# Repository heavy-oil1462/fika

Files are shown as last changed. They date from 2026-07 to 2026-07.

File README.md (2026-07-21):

# fika

An open source DIY cappuccino machine. Minimalist and solid: an oak
slab, two aluminum rails, exposed copper pipes and lead free brass, and
an ESP32 brain running ESPHome with first-class Home Assistant support.

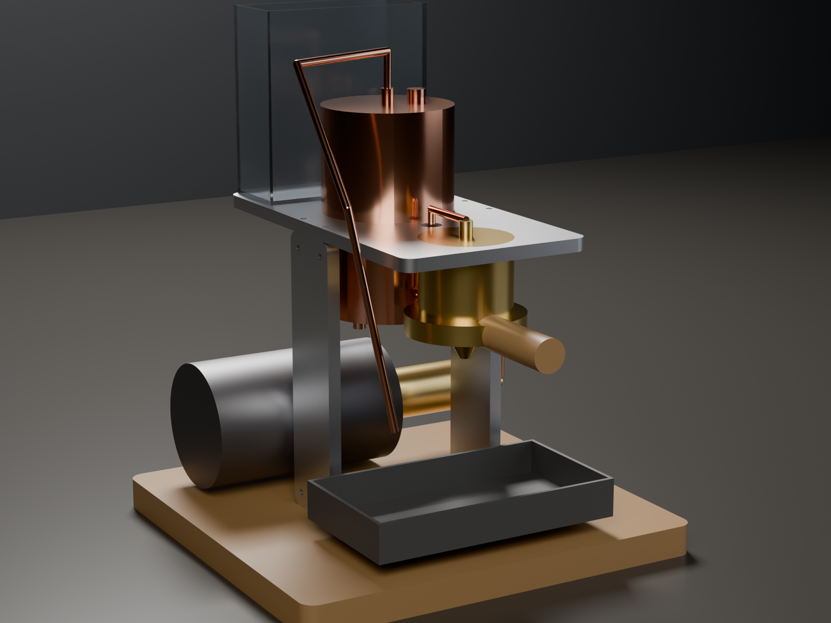
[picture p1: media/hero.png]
fika concept render


*Concept render, generated from the CAD by `scripts/render_hero.py`
(see the hero-render skill); regenerate, never edit. This machine does
not exist: the image shows design intent, not a product.*

## Status: early concept

This project is at the earliest possible stage. No machine exists and
none has ever been built: no frame has been cut, no boiler brazed, no
wire connected. What the repository contains is a parametric layout
model, a firmware skeleton that runs under QEMU, and documents
describing the design intent. Every dimension, setpoint, cost and
claim in these files is an unvalidated estimate and may change
completely. Nothing here is a build guide, and nothing here has been
reviewed for safety. Do not build from these files.

## Philosophy

- Controls are what you already do. Put your cup on the tray: the
  machine recognizes it by weight and arms that cup's brew program.
  Flip the solid brew toggle; the shot stops itself at the target
  beverage weight. Two toggles, a lamp, a beep. No screens.
- Autonomous. Every control loop runs on the ESP32; MQTT and Home
  Assistant observe and adjust setpoints. The machine brews with the
  network cable cut.
- Nothing that does not work. There is no case: the frame is an oak
  slab, two rails and a deck, and a member exists only if it carries a
  component (concepts/open-frame.md). What is left over is copper, so
  the plumbing is routed to be looked at.
- Solid and honest. Mains, heat and pressure are handled by a
  mechanical safety chain that works with the firmware dead
  (concepts/safety-architecture.md). Pressure parts are brass and
  copper, never printed; the parts you touch are oak.
- Deterministic. One parameters file drives CAD, layout checks and
  budgets; one command regenerates every derived artifact; one
  read-only gate verifies everything, runs before every push, and is
  exactly what CI runs.

## Design snapshot

- Single boiler, dual use: brew at 93 C, steam at 125 C (SPECS.md).
- Rotary vane pump + mains motor, OPV at 9 bar.
- 230 V / 50 Hz EU mains, 1400 W element, 10 A circuit friendly.
- Frame: 24 mm oak slab plus 10 mm 6082-T6 rails and deck, all cut on a
  PrintNC; DXF profiles are build products (outputs/dxf/).
- Layout at a glance: outputs/png/main_assembly.png, the fixed-camera
  reference render. Boiler and group seated in the deck, pump under it,
  tank standing on the deck, drip tray that doubles as a scale, exposed
  copper throughout.

## Control system

```
python3 tools/validate.py        # software gate (yaml, esphome, contracts)
scripts/verify_design.sh         # full read-only verify gate
python3 scripts/regen_all.py     # rebuild all derived artifacts
esphome config esphome/example-fika.yaml
```

Real-firmware simulation (no hardware needed): the actual compiled
firmware boots under Espressif QEMU and you poke sensor values from a
debug web page while watching the machine react. See docs/SIMULATION.md
and `.claude/skills/simulator`.

## Toolchain

Nix is optional everywhere. The software gate needs python3 plus
esphome, yamllint and the esphome_skills package: either
`pip install -r requirements.txt` or the pinned devshell
(`nix develop`). The CAD pipeline needs a 2024+
OpenSCAD dev snapshot, resolved as `$OPENSCAD`, then `openscad` on
PATH, then nix; the hero render needs any Blender 4.x the same way.
One caveat is honest by construction: derived artifacts are only
byte-reproducible between identical OpenSCAD builds, so the drift step
of the gate compares bytes when your version matches
outputs/openscad_version.txt and self-skips with a notice when it does
not, while every other step runs at full strength. CI runs the same
gate from pip and the OpenSCAD nightly AppImage, no nix involved.

## Repository structure

- `cad/` - OpenSCAD models; `design_params.scad` is the single source
  of truth for every shared dimension
- `outputs/` - committed build products (STL, DXF, PNG, budgets);
  regenerated by `scripts/regen_all.py`, drift-checked by the gate
- `media/` - the hero render; a build product of
  `scripts/render_hero.py`, kept out of outputs/ because Cycles output
  is not byte deterministic, so the gate cannot drift-check it
- `esphome/` - composable firmware: `fika-base.yaml` + one package per
  capability + example and simulator nodes
- `scripts/`, `tools/` - the pipeline and the gates
- `docs/` - contracts: PROTOCOL, HARDWARE, EXTENDING, SIMULATION
- `concepts/` - design rationale
- `.github/` - CI workflows, path-filtered: validate always, design on
  CAD-side changes, firmware on esphome changes
- `SPECS.md`, `MATERIALS.md`, `TODO.md`

## How to contribute

Fork, branch, and keep the gate green: `scripts/verify_design.sh` must
pass, and anything under `outputs/` must be regenerated in the same
change that alters its sources. Machine-specific configuration belongs
in your private fika-config (docs/EXTENDING.md), not in the stock
packages.

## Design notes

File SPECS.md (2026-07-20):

# fika technical specification

Numbered so discussions can cite sections. Dimensions and setpoints live
in cad/design_params.scad; this file states the design intent around
them. Status caveat: this is a concept-phase specification; none of it
has been built or validated (see Status in README.md).

## 1. Thermal

- Single dual-use boiler: copper shell, nominal 1.0 l fill, brass
  ports, lead free brazing. Vertical cylinder, element through the
  bottom cap.
- 1400 W / 230 V element behind an SSR, PID controlled (ESPHome
  climate). Setpoints: brew 93 C, steam 125 C, firmware cutoff 135 C.
- Heat-up budget from cold: under 6 min (generated proof:
  outputs/budgets/energy_budget.md; gate: verify step 7).

## 2. Hydraulic

- Rotary vane pump on a mains induction motor, low in the chassis for
  noise and center of gravity. OPV at 9 bar bypassing to the tank.
- Path: tank (gravity, standing on the deck above the pump) -> pump ->
  OPV tee -> boiler bottom -> front outlet -> three-way brew valve ->
  group; steam from the boiler top to the wand over the tray. Exposed
  copper lines, brass compression fittings.
- Boiler mechanical relief valve at 12 bar, venting over the tray.
- Group: standard 58 mm E61-compatible portafilter group (cots), bolted
  under the group mount plate.

## 3. Electrical

- 230 V / 50 Hz, 10 A circuit. Heater current 6.1 A leaves margin
  within the 80 percent continuous rule (generated budget).
- Heater path: mechanical thermal cutoff -> thermal fuse -> SSR.
  Pump motor via contactor. ESP32 and sensors are extra-low-voltage
  only. Pin map and wiring: docs/HARDWARE.md.

## 4. Controls

- ESP32 (esp32dev) running ESPHome; Home Assistant over MQTT discovery.
  All control loops local; the machine works with no network
  (docs/PROTOCOL.md).
- Physical controls: two solid toggles (brew, steam), a ready lamp, a
  buzzer. No screens.
- Behavior-driven: drip tray load cell recognizes calibrated cups by
  weight and arms that cup's brew program; shots stop gravimetrically
  at target beverage weight (concepts/cup-recognition.md).

## 5. Safety

- Three layers, firmware last and weakest:
  concepts/safety-architecture.md. Pressure and thermal parts are
  purchased, never printed.
- Every actuator defaults off at boot; actuator commands are never
  retained on the broker.

## 6. Frame and fabrication

- Open frame, no enclosure: an oak base slab, two aluminum rails, one
  aluminum deck. A member exists only if it carries a component
  (concepts/open-frame.md), so the copper runs are the visible surface
  of the machine.
- The deck seats the boiler and the group in bored seats, carries the
  tank, and passes the tank outlet and brew riser through two bores.
- Oak where hands and the counter meet the machine: the base slab and
  the portafilter handle (which must not conduct boiler heat).
- All flat parts are CNC-milled on the PrintNC, oak included; one bolt
  size (M5) throughout. DXF profiles are pipeline outputs
  (outputs/dxf/).
- Every cad part header carries a fabrication tag: cnc, print, cots,
  lib or assembly (gate: validate `fabtags`).

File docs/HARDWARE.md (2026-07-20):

# HARDWARE - electronics, pins and wiring

The mechanical and hydraulic BOM lives in MATERIALS.md. This file covers
the control electronics around the ESP32. Mains wiring is sketched here
for the contract only; SPECS.md section 5 and
concepts/safety-architecture.md define the safety chain that must exist
regardless of what the firmware does. Status caveat: concept phase;
none of this has been wired or tested on hardware (see Status in
README.md).

## Bill of materials (electronics)

| Qty | Part | Notes | ~Cost |
|---|---|---|---|
| 1 | ESP32 devkit (esp32dev) | the brain, 5 V USB supply | 5 EUR |
| 1 | Mean Well RS-15-5 or similar | 5 V PSU from mains | 10 EUR |
| 1 | SSR 25 A zero-crossing + heatsink | heater element switch | 10 EUR |
| 1 | Mechanical thermal cutoff, manual reset | on boiler shell, opens above max_temp_c | 5 EUR |
| 1 | Thermal fuse, one-shot | last resort, in series with the cutoff | 2 EUR |
| 1 | Relay/contactor, 230 V coil rating for motor load | pump motor switch | 8 EUR |
| 1 | Relay or MOSFET board | brew solenoid drive | 3 EUR |
| 1 | PT100 probe, M4 stud or pocket mount | boiler temperature | 8 EUR |
| 1 | MAX31865 breakout | PT100 amplifier, SPI | 5 EUR |
| 1 | TAL220 bar load cell, 1 kg | under the drip tray | 5 EUR |
| 1 | HX711 breakout | load cell amplifier | 3 EUR |
| 2 | Solid metal toggle switch | brew and steam controls | 8 EUR |
| 1 | Indicator lamp, 5 V | ready light | 2 EUR |
| 1 | Piezo buzzer, active | shot-finished beep | 1 EUR |

## Default pin map

Every pin is a substitution so a private fika-config can rewire without
touching the packages. Constraint column rules are hard: actuators must
never sit on strapping pins (GPIO0/2/12/15) that glitch at boot, and
GPIO34-39 are input only with no internal pulls.

| Function | GPIO | Substitution | Constraint |
|---|---|---|---|
| Heater SSR | GPIO25 | heater_pin | never a strapping pin |
| Pump relay | GPIO26 | pump_pin | never a strapping pin |
| Brew solenoid | GPIO27 | valve_pin | never a strapping pin |
| SPI clock | GPIO18 | spi_clk_pin | - |
| SPI MISO | GPIO19 | spi_miso_pin | - |
| SPI MOSI | GPIO23 | spi_mosi_pin | - |
| MAX31865 CS | GPIO5 | max31865_cs_pin | strapping pin, input at boot is fine for CS |
| HX711 DOUT | GPIO32 | hx711_dout_pin | - |
| HX711 SCK | GPIO33 | hx711_clk_pin | - |
| Brew switch | GPIO34 | brew_switch_pin | input only, external pull-down |
| Steam switch | GPIO35 | steam_switch_pin | input only, external pull-down |
| Ready lamp | GPIO21 | lamp_pin | - |
| Buzzer | GPIO22 | buzzer_pin | - |

## Wiring overview

    mains 230 V ---+--- 5 V PSU --- ESP32
                   |
                   +--- thermal cutoff --- thermal fuse --- SSR --- heater element
                   |                                         ^
                   |                                         | GPIO25
                   +--- contactor --- pump motor             |
                             ^                             ESP32
                             | GPIO26 (coil via driver)
                             |
                   +--- solenoid valve (via relay, GPIO27)

    ESP32 SPI (18/19/23/5) --- MAX31865 --- PT100 in boiler well
    ESP32 (32/33) --- HX711 --- load cell under drip tray
    GPIO34/35 --- brew / steam toggles (to 3V3 via switch, 10k pull-down)
    GPIO21/22 --- lamp / buzzer

The ESP32 side stays extra-low-voltage everywhere: it drives coils and
gates, never a mains conductor. Heater power flows through the
mechanical cutoff and the thermal fuse before the SSR, so two
independent hardware links open even if the SSR welds shut and the
firmware is gone.

## Calibration

Scale, two point: with the tray empty read the raw HX711 value into
`scale_raw_zero`; place a known 1000 g mass and read `scale_raw_1kg`.
Set both in your fika-config substitutions.

Cup table: weigh each cup empty on the calibrated tray, note the grams
into `cupN_tare_g`, pick `cupN_target_g` for the drink. Cups must differ
by more than 2 x cup_tolerance_g (10 g) or recognition refuses to guess
(by design, see concepts/cup-recognition.md).

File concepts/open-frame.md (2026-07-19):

# Open frame

**Purpose:** there is no case. The machine is held by three kinds of
member and nothing else, so every part you can see is a part that does
something.

## The rule

A member exists only if it carries a component. That leaves:

- the oak base slab: the mass that stands on the counter, damps the
  pump, and gives every other part something to bolt to,
- two aluminum rails: they carry the deck, flank the boiler on the way
  up, and touch nothing else (scripts/check_layout.py enforces the
  clearance),
- one aluminum deck: it seats the boiler and the group in bored seats,
  carries the tank, and passes the tank outlet and the brew riser
  through two more bores.

Panels, covers and a back wall carry nothing, so they are not in the
design. The consequence is that the copper is the visible surface of
the machine, which is why the runs are routed to be looked at rather
than hidden: shortest sensible path, right angles, no crossings.

## What follows from it

- Every layout number has to be honest, because nothing is concealed.
  The layout checks grew accordingly: rails clear all components, the
  deck leaves material around each bore, the tank sits on the deck, and
  nothing overhangs the slab.
- The tank stands on the deck rather than hanging in a cabinet, which
  puts its outlet well above the pump inlet and keeps the suction line
  flooded (concepts/single-boiler-thermal.md covers the thermal side).
- Hot parts are reachable by design, so the safety chain is mechanical
  and independent of firmware (concepts/safety-architecture.md), and
  the parts you touch are oak: the base and the portafilter handle.
- Stiffness has to come from the members themselves. The deck is a
  balanced beam, loaded by the group forward of the rails and the tank
  behind them; rail gussets are a phase 2 detail (TODO.md).

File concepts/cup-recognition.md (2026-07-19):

# Cup recognition

**Purpose:** the machine's controls should mostly be what the user
already does. Placing a cup on the tray is the order: the machine
recognizes which cup it is by weight and prepares that cup's drink, and
the shot stops itself at the right beverage weight.

## How

A bar load cell under the drip tray (cup_scale.yaml) weighs the tray
continuously. While idle, a stable weight within cup_tolerance_g of
exactly one calibrated cup tare selects that cup: the target beverage
weight is set and the detected cup is published. Flip the brew toggle
and the machine opens the valve, runs the pump, and stops
gravimetrically when beverage weight (current minus tare) reaches the
target.

## Rules that keep it honest

- Ambiguity selects nothing. Two cups within tolerance of the reading
  means no program is chosen; the machine never guesses. Calibrated
  tares must therefore differ by more than twice the tolerance.
- The matching rule exists once, in tools/cup_match.py, and the ESPHome
  lambda mirrors it line for line; tools/validate.py pins the shared
  tolerance and tools/test_cup_match.py pins the behavior.
- The brew toggle is still the commitment. Recognition arms a program,
  the human starts it; nothing pours because a cup appeared.
- No cup, no brew: the toggle logs a refusal if nothing was recognized.

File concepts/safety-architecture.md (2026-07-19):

# Safety architecture

**Purpose:** define the layered protection around 230 V mains, a
pressurized boiler and a 125 C surface, such that no single failure,
including a complete firmware failure, leaves the machine dangerous.

## Three layers, weakest last

1. Mechanical, always live. The heater circuit passes through a
   manual-reset thermal cutoff mounted on the boiler shell and a
   one-shot thermal fuse in series, before the SSR. The boiler carries a
   mechanical relief valve (relief_bar, 12 bar) that vents over the
   drip tray. The pump has an OPV (opv_bar, 9 bar) bypassing back to the
   tank. None of these know the ESP32 exists.
2. Electrical topology. The ESP32 side is extra-low-voltage everywhere;
   it drives the SSR input, a contactor coil and a solenoid driver.
   Actuator GPIOs avoid boot-glitching strapping pins and every actuator
   defaults off at boot (docs/HARDWARE.md).
3. Firmware interlocks (packages/safety.yaml). Over-temperature above
   max_temp_c or a dead boiler sensor latches a fault: heater off, pump
   off, valve closed, until the machine is power cycled. Steam mode and
   brewing exclude each other. This layer improves behavior; it is
   explicitly not the protection.

## Rules

- Pressure and thermal parts are cots brass/copper, never printed
  (MATERIALS.md marks them).
- The relief valve and OPV setpoints live in cad/design_params.scad;
  max_temp_c spans CAD and firmware and is swept by tools/validate.py.
- Any new actuator package must default off at boot and state its
  interlocks in the banner.

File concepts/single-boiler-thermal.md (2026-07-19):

# Single dual-use boiler

**Purpose:** one copper boiler serves both espresso water (~93 C) and
steam (~125 C), keeping the machine minimal: one vessel, one element,
one PID.

## Why single boiler

Dual boilers and heat exchangers buy simultaneous brew and steam at the
cost of a second vessel or muddier brew temperature control. fika's
aesthetic and philosophy is a small number of solid parts; waiting
half a minute between shot and milk is an accepted trade. The PID
retargets between two setpoints (steam_mode.yaml); brewing is
interlocked at steam temperature because 125 C water would scorch the
shot.

## Thermal notes

- 1.0 l fill, 1400 W element: about 4 min from cold to brew temperature
  (outputs/budgets/energy_budget.md is the generated truth; the verify
  gate keeps it under 6 min).
- The element enters the bottom cap; the PT100 sits in a well at mid
  height, away from the element so the PID sees water, not element skin.
- Steam is drawn from the top; brew water from low in the vessel via
  the front outlet. Fresh feed enters the bottom, which also tempers
  brew-temperature droop during a shot.
- The vessel is copper with brass ports, silver brazed with lead free
  alloy. Purchased or commissioned, never printed and never improvised
  (concepts/safety-architecture.md).

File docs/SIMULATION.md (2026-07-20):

# Simulating the machine - the real firmware, no hardware

fika ships a simulator that is not a re-implementation of the control
logic: it is the actual firmware, compiled for a stock esp32dev board
and executed under Espressif's QEMU fork, wired to your MQTT broker and
therefore your Home Assistant. The cup recognition, gravimetric stop,
PID retargeting and fault latching you observe are made by the same C++
that runs in the machine.

```
+------------------------- podman container --------------------------+
|                                                                     |
|  +-------------------------------+      +------------------------+  |
|  | QEMU (machine esp32)          | SNTP | webui.py               |  |
|  |  REAL firmware:               |----->|  simulated clock       |  |
|  |  sim-fika.yaml                | :123 |  sensor injections     |  |
|  |  = fika-base                  |      |  live entity view      |  |
|  |  + radio-openeth (emu eth)    |      +-----------^------------+  |
|  |  + sim-sensors (injectable)   |                  | http :8080    |
|  |  + REAL logic/actuators       |                  |               |
|  +---------------+---------------+                  |               |
+------------------+----------------------------------+---------------+
                   | MQTT (discovery, telemetry,      |
                   v        retained setpoints)     browser
            YOUR broker ---> YOUR Home Assistant
```

The simulator engine (container build, web UI, QEMU glue) lives in the
shared [esphome-skills](https://github.com/heavy-oil1462/esphome-skills)
package; the fika side is `tools/project.py` (injections, presets, node
names) and `tools/test_sim.py` (assertions).

## Quickstart

```bash
python3 tools/sim_container.py build                # once (~minutes)
python3 tools/sim_container.py run \
    --broker 192.168.1.10 --username fika --password ...
python3 tools/sim_container.py logs                 # firmware serial console
```

Open http://localhost:8080: sliders for the boiler temperature and cup
weight, toggles for the brew and steam switches, presets (cold start,
ready with cup, brewing), and a live view of everything the node
publishes. The node appears in Home Assistant via MQTT discovery as
`sim-fika`, indistinguishable from hardware.

The first `run` compiles the firmware inside the container against your
broker settings; the cache volume makes later starts fast. If the
broker runs on the container host, use `--broker
host.containers.internal` (the entrypoint resolves it to an IP before
baking it into the firmware; QEMU's user-mode network cannot see
container DNS).

## How each input reaches the real firmware

| Input | Mechanism |
|---|---|
| Sensor values | Retained MQTT topics `fika/<node>/sim/<key>`; packages/sim-sensors.yaml subscribes with the real entity ids (`boiler_temp`, `cup_weight`, `brew_switch`, `steam_switch`) so the stock logic packages run unmodified |
| Time of day | webui.py answers the firmware's SNTP queries (`sntp_server: 10.0.2.2`, re-sync every 15 s) with an offset clock |
| Setpoints | Nothing special: the standard retained command topics (PROTOCOL.md); edit `brew_target_weight` from HA or the UI like on hardware |

Until a value is injected a sensor has no state (NaN) and the
fail-safes behave exactly as with broken hardware: after
`sensor_grace_s` of NaN boiler readings, safety.yaml latches a fault.

Things worth trying: set the boiler to 93 and a cup of 210 g and watch
`detected_cup` flip to cappuccino and the lamp logic report ready; flip
brew and pour by raising cup_weight toward 360 g to see the gravimetric
stop; push the boiler past 135 to watch the fault latch kill the heater.

## The automated version: tools/test_sim.py

The same loop, CI-style: throwaway authenticated mosquitto, web UI
driven over HTTP, assertions on the broker:

```bash
sudo -E nix develop .#sim -c python3 tools/test_sim.py
```

Asserts boot + discovery, boiler_temp and cup_weight injection round
trips, cup recognition reacting to a 210 g cup, and switch injections
reaching their binary sensors. Requirements: an esphome that can
compile, `qemu-esp32` (in the `.#sim` devshell via the
nix-qemu-espressif flake input; kept out of the default shell because
it may build QEMU from source once), and the ability to bind udp/123
(root/CAP_NET_BIND_SERVICE; lwIP's SNTP port is not configurable).
Slow (a compile plus emulated boot time); deliberately not part of the
default validation gate.

## Limitations

- Not cycle-accurate: QEMU timing is roughly wall clock; good enough
  for second-scale brew logic, do not benchmark the PID on it.
- GPIO goes nowhere: the SSR, pump relay and valve drive emulated pins;
  observe actuators via their entities (which is what HA sees too).
- The PID heats nothing: boiler_temp only changes when you move the
  slider, so closed-loop thermal behavior cannot be studied, only the
  mode/setpoint/fault logic around it.
- OTA and safe mode exist but are pointless in a container that
  rebuilds from source each config change.

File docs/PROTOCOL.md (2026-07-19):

# PROTOCOL - the MQTT and entity id contract

This file is the contract between the firmware packages, the simulator,
Home Assistant, and any future consumer. If you change a semantic here,
change every producer and consumer in the same commit. tools/validate.py
(`protocol` check) asserts that the id table below exactly matches the
`Provides:` declarations in `esphome/packages/*.yaml`.

## Naming chain

One name flows through the whole stack. Rename only with a sweep across
all of them:

    entity name "Boiler Temperature"
      -> object_id boiler_temp
      -> MQTT topic fika/<node>/sensor/boiler_temp/state
      -> Home Assistant entity sensor.<node>_boiler_temperature

Topic tree: `<mqtt_root>/<node>/<component>/<object_id>/{state,command}`
with `mqtt_root` = `fika`. Text sensors pin their `state_topic`
explicitly so they never land in `sensor/` (see fika-base.yaml).

The temperature setpoints (`brew_temp_c`, `steam_temp_c`, `max_temp_c`)
also span `cad/design_params.scad` and the packages; tools/validate.py
(`temps` check) owns that sweep set.

## Retention rules

- Setpoints are retained (`brew_target_weight`): they must survive a
  restart or broker outage.
- Actuator commands are never retained (`pump`, `brew_valve`,
  `steam_mode`): a replayed command must not start a pump.
- `fika/<node>/status` is retained online/offline (broker LWT).
- Discovery messages are retained (`discovery_retain: true`).

All control loops run on the ESP32. MQTT and Home Assistant are
observation and setpoint adjustment only; the machine brews with the
network down.

## Entity id contract

| object_id | type | unit | retained command | provided by |
|---|---|---|---|---|
| boiler_temp | sensor | C | - | boiler_sensor, sim-sensors |
| boiler | climate | C | no | boiler_pid |
| heater_duty | sensor | % | - | boiler_pid |
| steam_mode | switch | - | no | steam_mode |
| pump | switch | - | no | pump |
| brew_valve | switch | - | no | brew_valve |
| cup_weight | sensor | g | - | cup_scale, sim-sensors |
| scale_tare | button | - | no | cup_scale |
| detected_cup | text_sensor | - | - | cup_logic |
| brew_target_weight | number | g | yes | cup_logic |
| beverage_weight | sensor | g | - | cup_logic |
| brewing | binary_sensor | - | - | cup_logic |
| brew_switch | binary_sensor | - | - | switches, sim-sensors |
| steam_switch | binary_sensor | - | - | switches, sim-sensors |
| machine_status | text_sensor | - | - | status |
| fault | binary_sensor | - | - | safety |

Interoperability rule: swapping hardware means writing a package that
provides the same object_id with the same unit. Nothing else may need to
change.

`machine_status` values: `heating`, `ready`, `brewing`, `steam`,
`fault`. `detected_cup` values: a calibrated cup name or `none`.

## Simulator injection topics

The simulator (docs/SIMULATION.md) feeds sensors through retained
topics of the form `fika/<node>/sim/<key>`:

    fika/sim-fika/sim/boiler_temp     float C
    fika/sim-fika/sim/cup_weight      float g
    fika/sim-fika/sim/brew_switch     0/1
    fika/sim-fika/sim/steam_switch    0/1

tools/validate.py (`sim` check) asserts these keys equal the web UI's
INJECTIONS and the mqtt_subscribe topics in packages/sim-sensors.yaml.

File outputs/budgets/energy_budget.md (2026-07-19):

# Energy budget

Generated by tools/energy_budget.py from cad/design_params.scad.
Regenerate with scripts/regen_all.py, never edit by hand.

## Electrical

- heater power: 1400 W at 230 V
- heater current: 6.09 A
- breaker: 10 A, continuous limit 8.0 A (80%)
- margin to continuous limit: 1.91 A

## Thermal

- boiler fill: 1.00 kg water, shell 1.21 kg copper
- ambient 20 C to brew 93 C: 340 kJ
- heat-up at 1400 W: 4.0 min
- margin to the 6 min budget: 2.0 min

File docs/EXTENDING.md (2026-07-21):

# EXTENDING - adapt fika without forking it

The core rule from frodas applies unchanged: base and the stock packages
are never edited for a specific machine. Your configuration is a package
list plus substitutions.

## Your private fika-config

Keep your node config (pins, cup table, secrets) in a private repo
cloned inside your fika checkout; fika gitignores `fika-config/`:

    cd fika
    git clone <your-private-config-repo> fika-config
    esphome run fika-config/fika.yaml

Start it by copying `esphome/example-fika.yaml` and
`esphome/secrets.yaml.example`, keep the packages your build has
hardware for, and override substitutions:

    substitutions:
      cup1_name: lungo
      cup1_tare_g: "138.0"
      cup1_target_g: "90.0"
      heater_pin: GPIO25

    packages:
      base: !include ../esphome/fika-base.yaml
      radio: !include ../esphome/packages/radio-wifi.yaml
      # ... the stock list from example-fika.yaml

Alternatively use ESPHome remote packages pinned by ref against
github.com/heavy-oil1462/fika.

## Adding hardware

New hardware means a new package, not an edit. Write
`packages/sensor-<thing>.yaml` with the boxed banner (Substitutions and
Provides sections; the Provides ids are parsed by tools/validate.py) and
provide existing object_ids where you replace stock hardware: a package
that publishes `boiler_temp` in C is a drop-in boiler sensor whatever
the silicon (docs/PROTOCOL.md, interoperability rule).

## Adding a cup

The stock table has two cups as substitutions (cup_logic.yaml). More
cups currently means extending cup_logic.yaml's lambda and the mirror in
tools/cup_match.py together, plus tools/test_cup_match.py; the table is
deliberately substitutions-only until someone needs more than a few
cups. Keep tares at least 2 x cup_tolerance_g apart.

## Checks

Whatever you change: `python3 tools/validate.py`, and before any commit
`scripts/verify_design.sh` (the verify skill). CI runs the same gate
(.github/workflows/), so a green local run means a green PR.

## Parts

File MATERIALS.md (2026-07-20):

# Material and component list (BOM)

Grouped by subsystem. CAD back-references point at the owning model.
The electronics detail table with costs lives in docs/HARDWARE.md.
Pressure and thermal parts are cots only: never printed, never
improvised. Status caveat: this is a concept-phase list; no part on it
has been bought or fitted (see Status in README.md).

## Frame and mechanics

The frame is open: three members, each carrying a component
(concepts/open-frame.md). DXF profiles for all of them are pipeline
outputs in outputs/dxf/.

- European oak slab, 24 mm, 330 x 320: the base everything bolts to
  (cad/frame.scad, profile `base`). Cut on the PrintNC like the metal.
  Oiled, not lacquered, so it can be re-oiled after spills.
- 6082-T6 aluminum plate, 10 mm: two rails (profile `rail`) and one
  deck (profile `deck`). The deck is bored to seat the boiler and the
  group and to pass the tank outlet and brew riser.
- M5 stainless bolts throughout, one bolt size for every frame joint
  (bolt_hole_d in cad/design_params.scad). Threaded inserts in the oak.
- Printed drip tray, PETG (cad/drip_tray.scad); replace with folded
  stainless later (TODO phase 2).

## Boiler and thermal (cots only)

- Copper boiler, ~102 mm OD x 160 mm, 1.0 l, brass ports
  (cad/boiler.scad envelope). Commissioned or salvaged; lead free
  brazing.
- Heating element 1400 W / 230 V, bottom entry.
- Mechanical relief valve, 12 bar.
- Thermal cutoff (manual reset) and one-shot thermal fuse, boiler
  shell mount.
- PT100 probe + MAX31865 (docs/HARDWARE.md).
- Insulation wrap for the shell (keeps the exposed-copper look on the
  pipes, not the vessel).

## Hydraulics (cots only)

- Rotary vane pump head, Procon/Fluid-o-Tech class (cad/pump.scad
  envelope), with 9 bar OPV.
- Mains induction motor, ~100 mm frame (cad/pump.scad envelope).
- Three-way brew solenoid valve, 230 V.
- 58 mm portafilter group (cad/group.scad envelope), with a turned oak
  handle: the one part of the group you hold, and the one that must not
  conduct boiler heat into your hand.
- Copper tube 6 mm OD (pressure and steam), 8 mm OD (suction), lead
  free brass compression fittings (cad/hydraulic_path.scad).
- Water tank ~1.3 l, glass or stainless, standing on the deck so the
  suction line stays flooded (cad/tank.scad envelope).

## Electronics

- See the table in docs/HARDWARE.md (ESP32, SSR, contactor, MAX31865,
  HX711 + TAL220 load cell, toggles, lamp, buzzer, 5 V PSU).

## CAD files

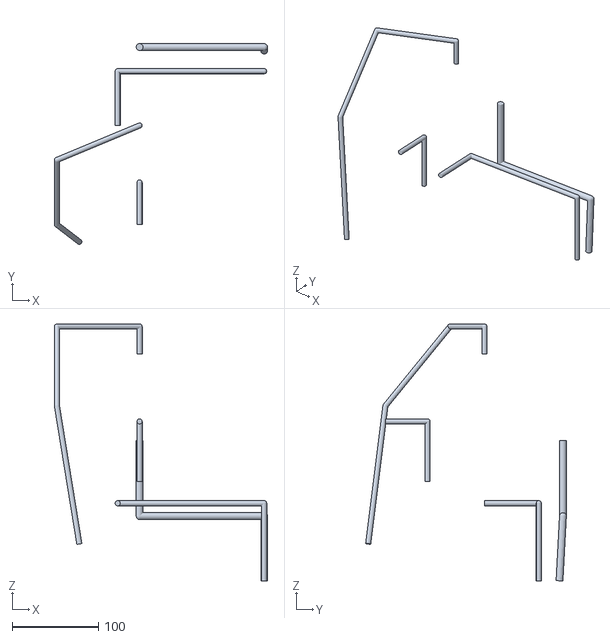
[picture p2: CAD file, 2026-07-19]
outputs/stl/hydraulic_path.stl
247.5 x 233.0 x 298.2

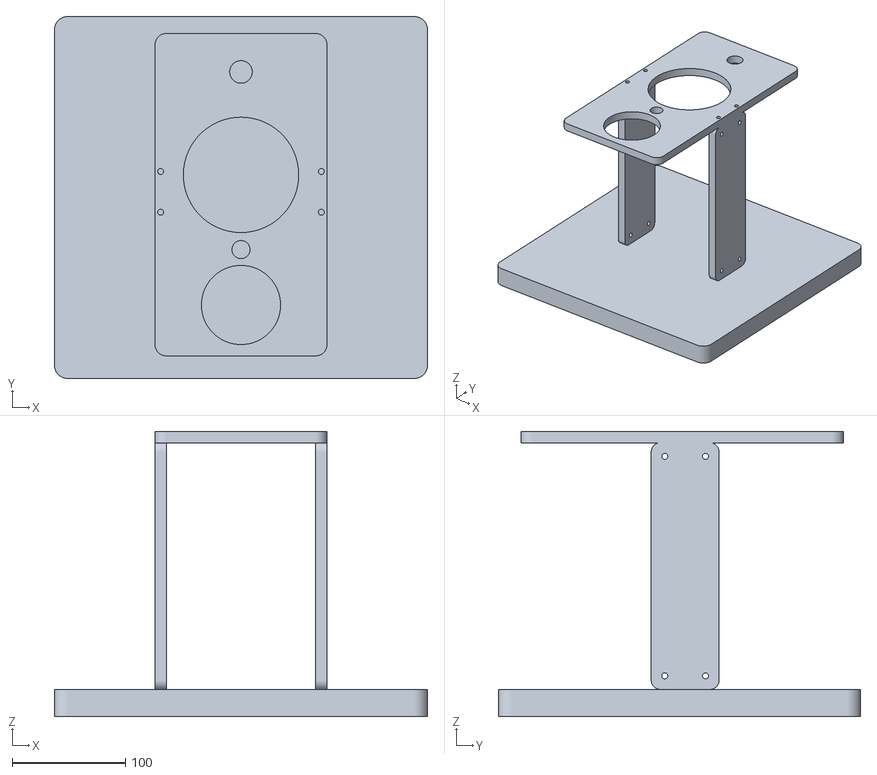
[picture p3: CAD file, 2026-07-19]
outputs/stl/frame.stl
330.0 x 320.0 x 252.0

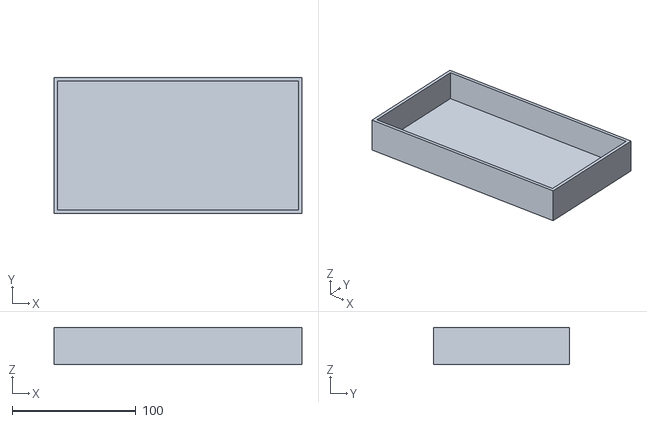
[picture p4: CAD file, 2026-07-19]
outputs/stl/drip_tray.stl
200.0 x 110.0 x 30.0

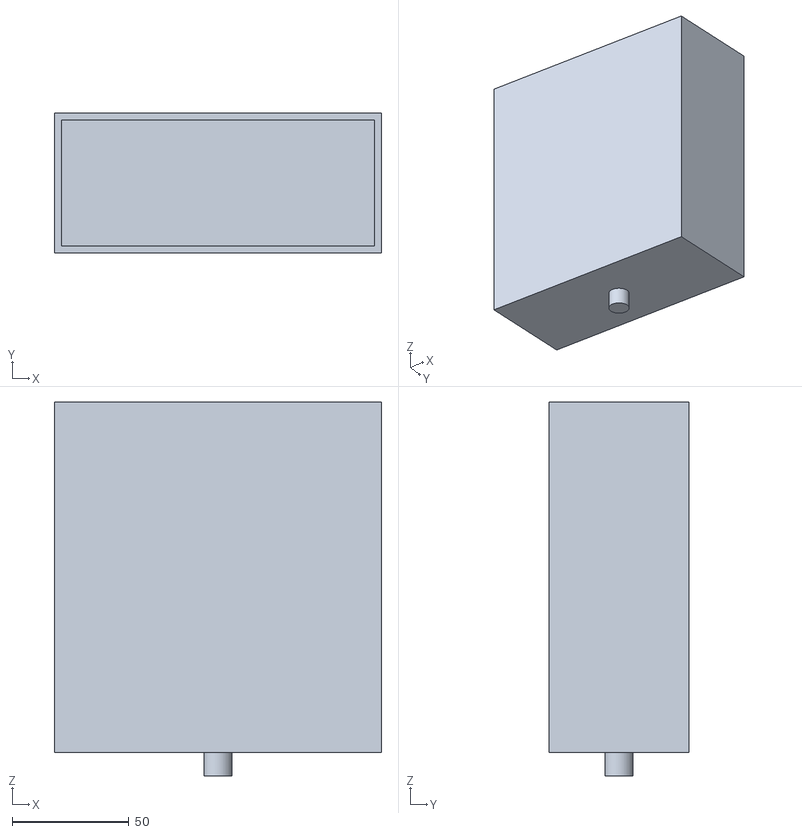
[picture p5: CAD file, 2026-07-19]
outputs/stl/tank.stl
140.0 x 60.0 x 160.0

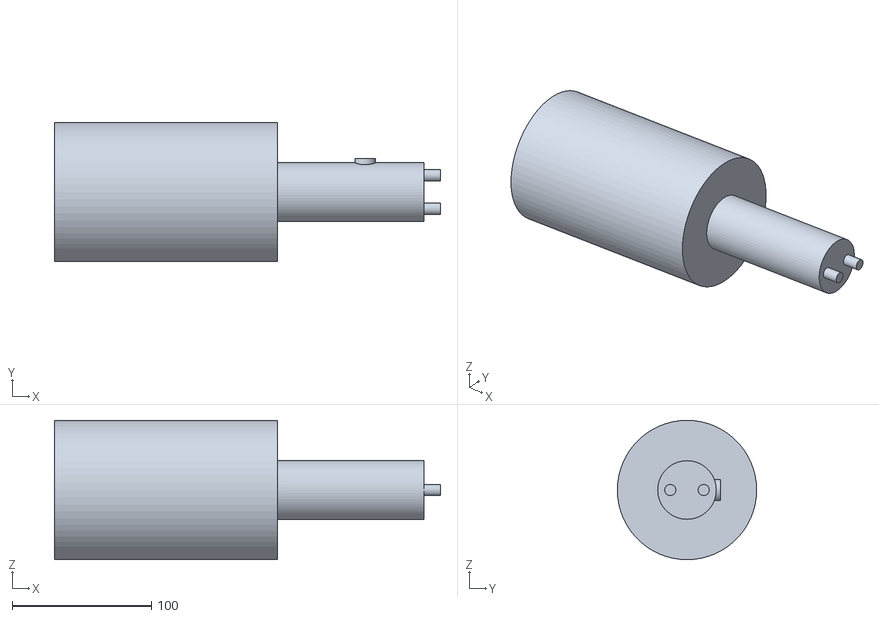
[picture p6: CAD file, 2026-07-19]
outputs/stl/pump.stl
277.0 x 100.0 x 100.0

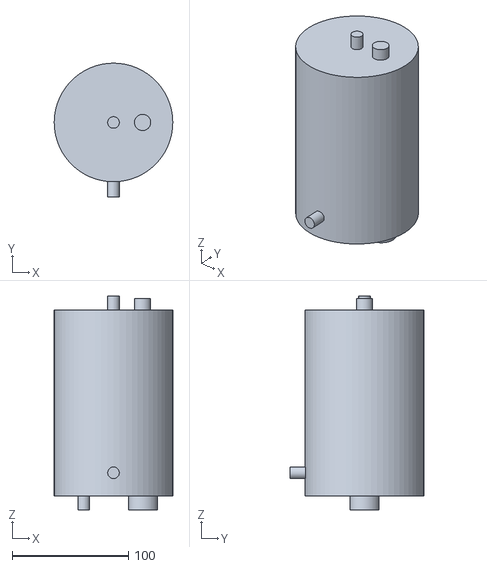
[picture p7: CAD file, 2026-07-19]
outputs/stl/boiler.stl
102.0 x 115.0 x 184.0

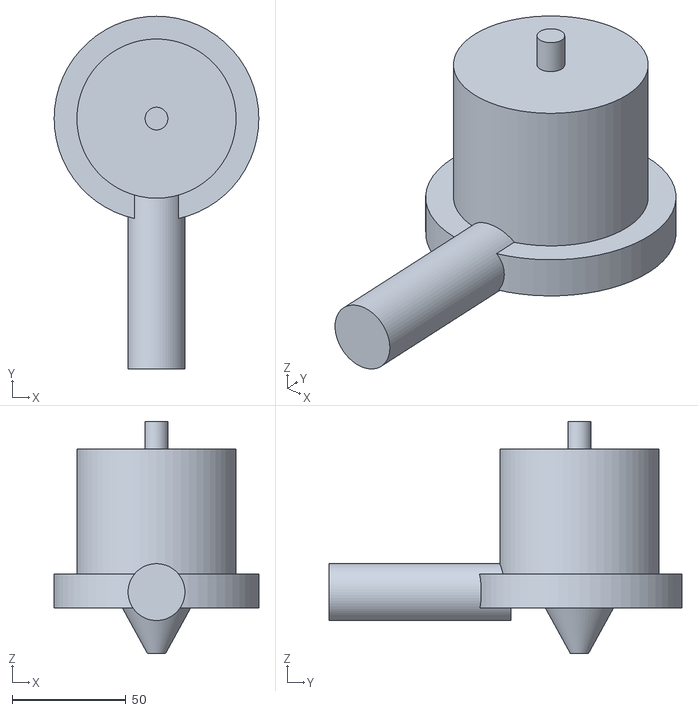
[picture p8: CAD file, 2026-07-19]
outputs/stl/group.stl
90.0 x 155.0 x 102.0

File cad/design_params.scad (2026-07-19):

/*
 * fika - shared design parameters, the single source of truth.
 *
 * Read by every cad/*.scad (include <design_params.scad>) and re-parsed by
 * scripts/design_params.py for scripts/check_layout.py and
 * tools/energy_budget.py, so a value changed here flips the whole pipeline
 * at once. scripts/check_params.py fails the build if any other .scad
 * shadows a name defined here.
 *
 * Keep every line a plain literal: name = value; (numbers, booleans, flat
 * vectors). No arithmetic - derived values are computed by the consumers.
 *
 * Units: mm, deg C, W, V, A, bar, g unless noted.
 * Coordinates: origin at the center of the base plate top surface.
 * X right, Y toward the back, Z up. Positions are component reference
 * points noted per name.
 */

// open frame: an oak base slab carrying two aluminum rails and one deck
// plate that holds the boiler and the group through bored seats. There is
// no enclosure - every member carries a component, and everything else is
// left exposed. Heights are derived from the components they hold.
frame_w = 330;          // base slab width (clears the pump and its ports)
frame_d = 320;          // base slab depth
base_t = 24;            // oak slab thickness (mass and damping; z -base_t..0)
frame_plate_t = 10;     // aluminum rails and deck
rail_inset = 66;        // rail inner face from center (flanks the boiler)
rail_front = 135;       // rail front edge (clears the drip tray)
rail_back = 195;        // rail back edge (clears the pump)
deck_front = 20;        // deck front edge (leaves plate around the group bore)
deck_back = 305;        // deck back edge (carries the tank behind the boiler)

// boiler (single, dual use, copper shell; position = bottom center)
boiler_od = 102;
boiler_h = 160;
boiler_wall = 2;
boiler_x = 0;
boiler_y = 180;
boiler_z = 150;
boiler_volume_l = 1.0;  // nominal fill, used by the energy budget

// heater and mains
heater_power_w = 1400;
mains_voltage = 230;
mains_breaker_a = 10;
brew_temp_c = 93;
steam_temp_c = 125;
max_temp_c = 135;       // firmware hard cutoff; mechanical cutoff above this

// pump: rotary vane head + mains motor, axis along X at the rear base
// (position = axis center; assembly centered on pump_x)
pump_head_d = 42;
pump_head_l = 105;
motor_d = 100;
motor_l = 160;
pump_x = 0;
pump_y = 255;
pump_z = 55;
opv_bar = 9;            // pump bypass back to reservoir
relief_bar = 12;        // boiler mechanical safety relief valve

// brew group and cup zone (position = group axis at tray center)
group_od = 70;
group_h = 90;
group_x = 0;
group_y = 65;
cup_clearance_h = 95;   // spout height above the tray top
cup_max_d = 90;

// drip tray with load cell scale (tray_z = top of load cell + gap)
tray_w = 200;
tray_d = 110;
tray_h = 30;
tray_y = 15;            // tray front edge
tray_z = 13;
loadcell_l = 55;        // TAL220-class bar load cell
loadcell_w = 12.7;
loadcell_h = 12.7;
scale_capacity_g = 1000;

// water tank: stands on the deck behind the boiler, so the outlet sits
// well above the pump inlet and the suction line stays flooded.
// tank_z must equal the deck top (scripts/check_layout.py asserts it).
tank_w = 140;           // stays within the deck it stands on
tank_d = 60;
tank_h = 150;
tank_y = 241;
tank_z = 228;

// plumbing, copper lines (suction from the tank is larger bore)
brew_line_od = 6;
brew_line_wall = 1;
steam_line_od = 6;
suction_line_od = 8;

// fasteners (one bolt size for every frame joint, M5 with clearance)
bolt_hole_d = 5.3;

// layout rules (scripts/check_layout.py)
clearance = 10;         // minimum gap between component envelopes, and
                        // between the rails and anything they do not carry

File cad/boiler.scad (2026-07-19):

/*
 * fika - boiler envelope.
 * Purpose: layout placeholder for the single dual-use copper boiler.
 *          Origin at the bottom cap center. Stubs mark the ports: element
 *          boss and feed inlet below, brew outlet on the front face low,
 *          steam outlet and safety relief valve on top.
 * Material: copper shell, brass ports (pressure vessel, never printed)
 * Fabrication: cots
 */

include <design_params.scad>

$fn = 60;

module boiler() {
    color("#b87333") {
        cylinder(d = boiler_od, h = boiler_h);
        // heating element boss, enters through the bottom cap
        translate([boiler_od / 4, 0, -12]) cylinder(d = 25, h = 14);
        // feed water inlet from the pump
        translate([-boiler_od / 4, 0, -12]) cylinder(d = 10, h = 14);
        // brew outlet to the group, front face, low
        translate([0, -boiler_od / 2 + 2, 20])
            rotate([90, 0, 0]) cylinder(d = 10, h = 15);
        // steam outlet, top center
        translate([0, 0, boiler_h]) cylinder(d = 10, h = 12);
        // safety relief valve port, top
        translate([25, 0, boiler_h]) cylinder(d = 14, h = 10);
    }
}

boiler();

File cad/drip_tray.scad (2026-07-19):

/*
 * fika - drip tray and load cell.
 * Purpose: layout placeholder for the drip tray that doubles as the cup
 *          scale platform. Tray origin at the center of its footprint,
 *          bottom at z 0. loadcell_bar() is the TAL220-class bar the tray
 *          sits on, placed by the assembly between base plate and tray.
 * Material: printed tray for the foundation, load cell off the shelf
 * Fabrication: print
 */

include <design_params.scad>

$fn = 60;

module drip_tray() {
    color("#333333") difference() {
        translate([-tray_w / 2, -tray_d / 2, 0])
            cube([tray_w, tray_d, tray_h]);
        translate([-tray_w / 2 + 3, -tray_d / 2 + 3, 4])
            cube([tray_w - 6, tray_d - 6, tray_h]);
    }
}

// cots: bar load cell under the tray center
module loadcell_bar() {
    color("#999999") translate([-loadcell_l / 2, -loadcell_w / 2, 0])
        cube([loadcell_l, loadcell_w, loadcell_h]);
}

drip_tray();

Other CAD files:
outputs/dxf/frame_base.dxf
outputs/dxf/frame_deck.dxf
outputs/dxf/frame_rail.dxf
cad/frame.scad
cad/group.scad
cad/hydraulic_path.scad
cad/main_assembly.scad
cad/pump.scad
cad/tank.scad

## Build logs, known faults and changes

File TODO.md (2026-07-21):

# TODO

## Phase 1 - foundation (this PR)

- [x] Repo conventions: params single source of truth, guards, flake
- [x] Layout CAD: frame, envelopes, hydraulic path, assembly, DXF/STL/PNG
- [x] Pipeline: regen_all + read-only verify gate + drift check
- [x] Firmware skeleton: base, packages, contracts, example + sim nodes
- [x] QEMU simulator with injection web page
- [x] Docs: SPECS, MATERIALS, PROTOCOL, HARDWARE, EXTENDING, concepts
- [x] CI running the verify gate (.github/workflows/: validate on every
      change, the full design gate and the firmware build path-filtered;
      no nix in CI - pip plus the OpenSCAD snapshot AppImage, byte drift
      self-skips unless the version matches outputs/)

## Phase 2 - mechanical detail

- [ ] Rail stiffness: the deck is a balanced beam on two slender rails,
      so size the rails properly or add gussets at the slab and deck
- [ ] Frame joinery: threaded inserts in the oak, real hole patterns
- [ ] Boiler seat detail: a collar in the deck bore, not a bare hole
- [ ] Boiler sourcing decision and exact port layout
- [ ] Pump/motor mounts, vibration isolation into the oak
- [ ] Group mount detail, portafilter clearance check against a real group
- [ ] Stainless drip tray, load cell mount detail
- [ ] Steam wand articulation and an oak grip on the wand
- [ ] Copper routing detail with real bend radii, mesh interference check

## Phase 3 - electronics bring-up

- [ ] Bench: ESP32 + MAX31865 + HX711 + relays on a board
- [ ] Scale calibration procedure validated, cup table for real cups
- [ ] Mains box: SSR heatsinking, contactor, safety chain wiring

## Phase 4 - firmware maturation

- [ ] PID tuning against the real boiler
- [ ] Pre-infusion and shot timing, pressure sensing decision
- [ ] MQTT protocol integration test (port frodas test_protocol.py)
- [ ] HA dashboard package

## Phase 5 - full build

- [ ] Assembly, plumbing, first shots
- [ ] Steam wand articulation
- [ ] Documentation photos, build guide

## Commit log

2026-07-19 Toolchain and conventions: flake devshells, params source of truth, guards
    Ports proven pieces from the sibling repos: scripts/check_params.py and
    scripts/design_params.py from starling (with a FIKA_ env prefix and a -D
    forwarding helper), scripts/render_scad.sh from PrintTrek, tools/_lib.py
    and the flake devshell layout from frodas. cad/design_params.scad seeds
    the shared dimensions for the whole machine.
    [design_params.scad]
2026-07-19 CAD layout: frame, component envelopes, hydraulic path, assembly
    Layout-level models in machine coordinates, all dimensions from
    design_params.scad. Frame is five CNC aluminum plates with DXF profile
    export via -D export_profile. Boiler, pump, group, tank and load cell
    are cots envelopes with port stubs; the drip tray is printed. The
    hydraulic path models the four exposed copper runs. Verified by
    rendering: assembly PNG matches the intended layout, frame and
    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
    [boiler.scad, design_params.scad, drip_tray.scad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]
2026-07-19 Pipeline and gates: regen_all, verify_design, validators, first outputs
    Two entry points own everything derived: scripts/regen_all.py rebuilds
    STLs, CNC DXF profiles, fixed-camera PNGs and the energy budget from a
    single parts manifest, and scripts/verify_design.sh is the read-only
    eight-step gate (byte-compile, params guard, software gate, regen with
    warnings as errors, STL shell counts, layout clearances, budget
    assertions, byte-for-byte drift against committed outputs).
    tools/cup_match.py is the pure python statement of cup recognition and
    gravimetric stop, pinned by unit tests; validate.py cross-checks it
    against the firmware lambda and sweeps the temperature setpoints
    against design_pa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
    [boiler.stl, drip_tray.stl, frame.stl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]
2026-07-19 Regenerate assembly render after the group handle fix
    The verify drift check caught that the committed PNG predated the
    portafilter handle move.
2026-07-19 Firmware skeleton and QEMU simulator
    Composable ESPHome in the frodas mold: fika-base (always-on transport,
    MQTT discovery, snapshot on connect) plus one package per capability
    with banner-documented Substitutions and Provides ids. Boiler PID over
    a slow-PWM SSR output, steam mode retargeting with pump interlock,
    gpio pump and brew valve defaulting off, HX711 cup scale, cup logic
    mirroring tools/cup_match.py (recognition, ambiguity refusal,
    gravimetric stop), physical toggles, lamp/buzzer status, and a latching
    over-temperature/dead-sensor fault package.
    The simulator runs this real firmware under Espressif QEMU in a
    container with a web page injecting boiler_temp, cup_weight and the
    switch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
    [boiler_pid.yaml]
2026-07-19 Docs, skills and CI
    SPECS, MATERIALS, TODO, README with the pipeline-rendered hero, docs
    contracts (PROTOCOL id table asserted by validate, HARDWARE pin map
    and wiring, EXTENDING, SIMULATION), Purpose-first concepts pages, five
    skills (verify, regen-outputs, openscad-review, firmware, simulator),
    and a CI workflow running exactly the local verify gate, which the
    sibling repos intended but never wired.
2026-07-19 Defer the CI workflow: the push token lacks the workflow scope
    The verify gate stays the CI contract and runs locally before every
    push; TODO.md tracks wiring the one-job workflow once the token allows.
2026-07-19 Open frame in oak and aluminum: no enclosure, every member carries something
    The box is gone. The frame is now an oak base slab, two aluminum rails
    and one deck plate, and a member only exists if it holds a component:
    the slab is the mass on the counter and the thing everything bolts to,
    the rails carry the deck and touch nothing else, and the deck seats the
    boiler and the group in bored seats, carries the tank, and passes the
    tank outlet and brew riser through two more bores. Oak goes where hands
    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
    [design_params.scad, drip_tray.stl, frame.scad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]
2026-07-20 State clearly that the project is an unbuilt early concept
    The repo reads like a finished, buildable design. Add a status section
    at the top of the README saying no machine exists and nothing is
    validated, plus one-line caveats in SPECS, MATERIALS and HARDWARE, the
    files most likely to be mistaken for build instructions.
2026-07-20 Photoreal hero render pipeline and README hero image
    scripts/render_hero.py exports the master assembly as a colored 3MF
    (the color() tags in cad/ are the material tags), splits it into one
    mesh per material, and renders a studio scene in headless Blender
    Cycles (scripts/hero_scene.py). The result is committed as
    media/hero.png and becomes the README hero, with a caption saying
    plainly that the machine does not exist.
    media/ sits outside outputs/ on purpose: Cycles output is not byte
    deterministic across machines, so the drift gate cannot own it. The
    pinned nixpkgs channel moves to scripts/nixpkgs_channel, shared by
    render_scad.sh and render_hero.py. New hero-render skill documents
    the comm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
2026-07-20 Migrate software tooling to the shared esphome-skills package
    The tooling engine (validation framework and generic checks, sim
    container + web UI + QEMU glue + test harness, devshell construction)
    now comes from the esphome-skills flake input. This repo keeps only its
    own substance: tools/project.py (names, injections, presets), the
    CAD-coupled checks (fabtags, protocol table, cup logic mirror,
    temperature sweep) in tools/validate.py, and the sim test assertions.
    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
2026-07-21 CI wiring and a nix-free toolchain path for the verify gate
    Three path-filtered workflows mirror the pourbot setup: validate runs
    the software gate on every change, design runs the full verify gate on
    CAD-side changes with the OpenSCAD snapshot AppImage under xvfb, and
    firmware compiles both nodes with pip esphome and cached build trees.
    They supersede the nix-based draft parked at ci/github-ci.yml.
    Nix becomes optional everywhere so external CI and contributors can
    run the toolchain without it. requirements.txt (esphome-skills,
    esphome, yamllint) covers the software gate; render_scad.sh resolves
    OpenSCAD as $OPENSCAD, then a 2024+ openscad on PATH, then nix;
    render_hero.py resolves Blender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
